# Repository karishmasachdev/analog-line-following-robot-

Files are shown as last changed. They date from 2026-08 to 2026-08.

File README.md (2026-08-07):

# analog-line-following-robot — Custom PCB Design

A line-following robot built entirely from discrete analog components — no microcontroller, no programmable logic. This repo covers the full circuit design and my custom KiCad schematic/PCB layout, built on top of a line-following robot.

## Overview

The robot follows a black line on a white surface using visible-light sensing, analog comparison, and transistor-driven motors — all without any digital logic or code. The signal path has three stages:

- **Sensing** — a pair of LDR (photoresistor) voltage dividers, each paired with a white LED that actively floods the surface below the robot with light
- **Comparison** — the LM358 package's two op-amps are each wired as a comparator using the same left-row and right-row voltages, but with the `+`/`−` inputs swapped between them: one op-amp takes the left row on `+` and the right row on `−`, the other takes the right row on `+` and the left row on `−`. This produces two separate, naturally complementary outputs — one op-amp per motor — instead of a single shared output
- **Actuation** — the comparator output drives BJTs (acting as switches) that control current to two DC gear motors, steering the robot by adjusting each wheel's power independently

## How it works

Each LDR sits in a voltage divider with its own potentiometer, one row for the left sensor and one for the right. When a surface reflects more light back into an LDR, that LDR's resistance drops and its row's voltage falls; over the black line, less light returns, resistance rises, and the row's voltage climbs. The two rows are compared directly against each other rather than against a fixed threshold.

Each op-amp takes the left row's voltage and the right row's voltage as its two inputs, but with the `+` and `−` connections reversed relative to the other op-amp. Because of that reversal, when one side reads higher than the other, the two op-amp outputs snap in opposite directions — one goes high while the other goes low — rather than passing through a slow analog gradient. Each output feeds the base of its own NPN BJT, switching that motor's current on or off. Flyback diodes across each motor protect the transistors from voltage spikes when the motor switches off, and electrolytic capacitors across the power rails smooth out ripple from the motors starting and stopping.

Because the two op-amp outputs are naturally complementary (one high while the other is low, and vice versa), the two motors respond oppositely to the same left-vs-right comparison: when the robot drifts and one sensor row reads higher relative to the other, one motor speeds up while the other slows or stops, steering the robot back onto the line.

## Repo contents

```
├── kicad/              KiCad project, schematic, and PCB layout files
├── images/
│   ├── schematic.png
│   ├── pcb-layout.png
│   └── 3d-render.png
└── media/
    └── demo-video link
```

## Schematic

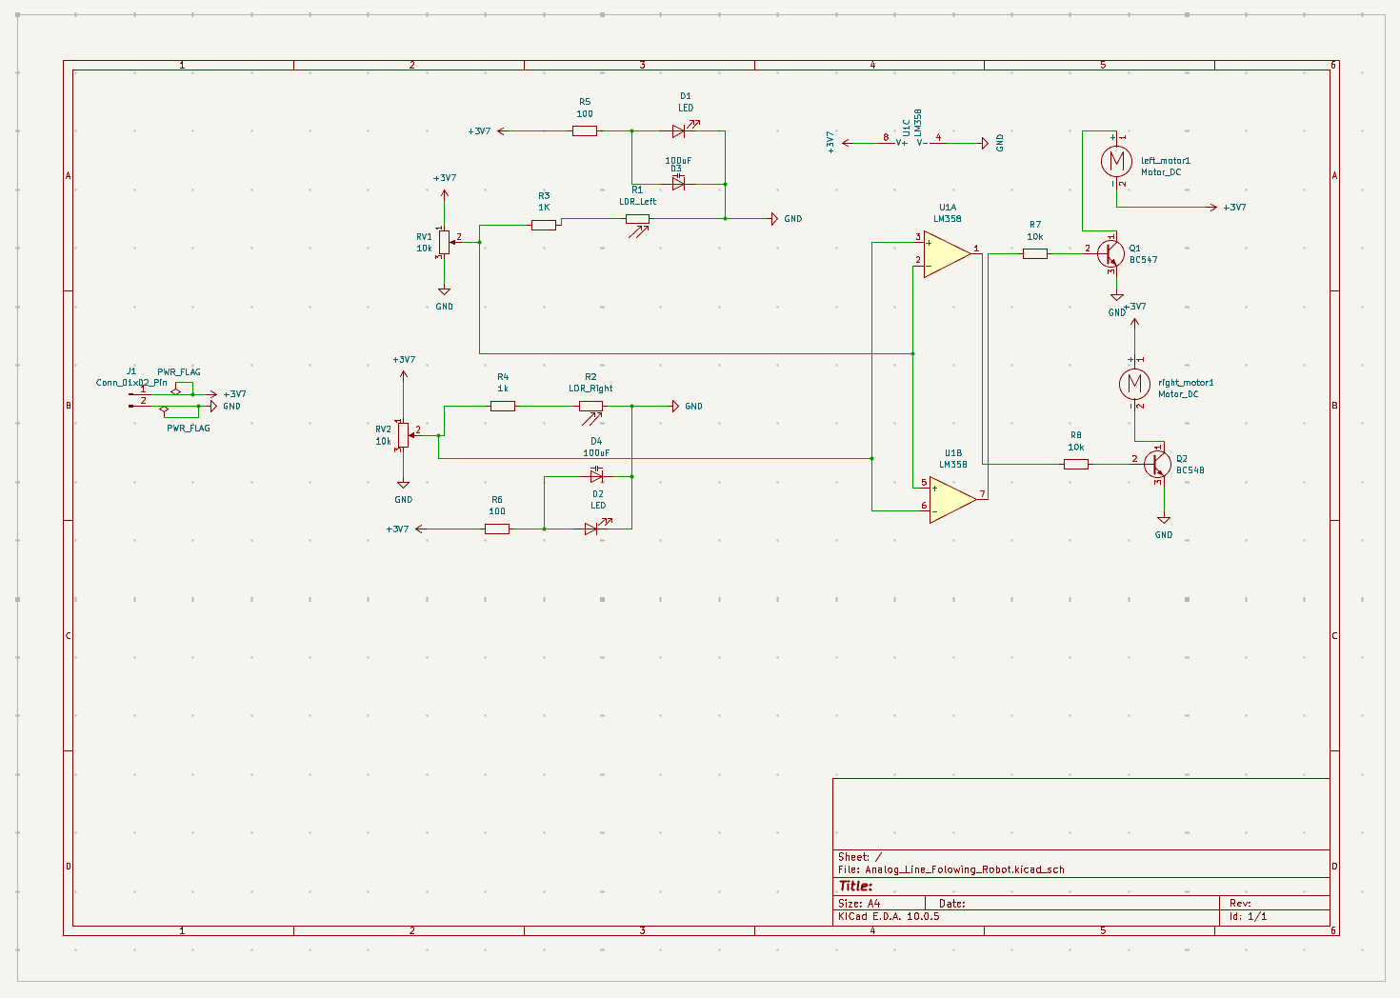
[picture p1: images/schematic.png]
schematic


## PCB layout (routed)

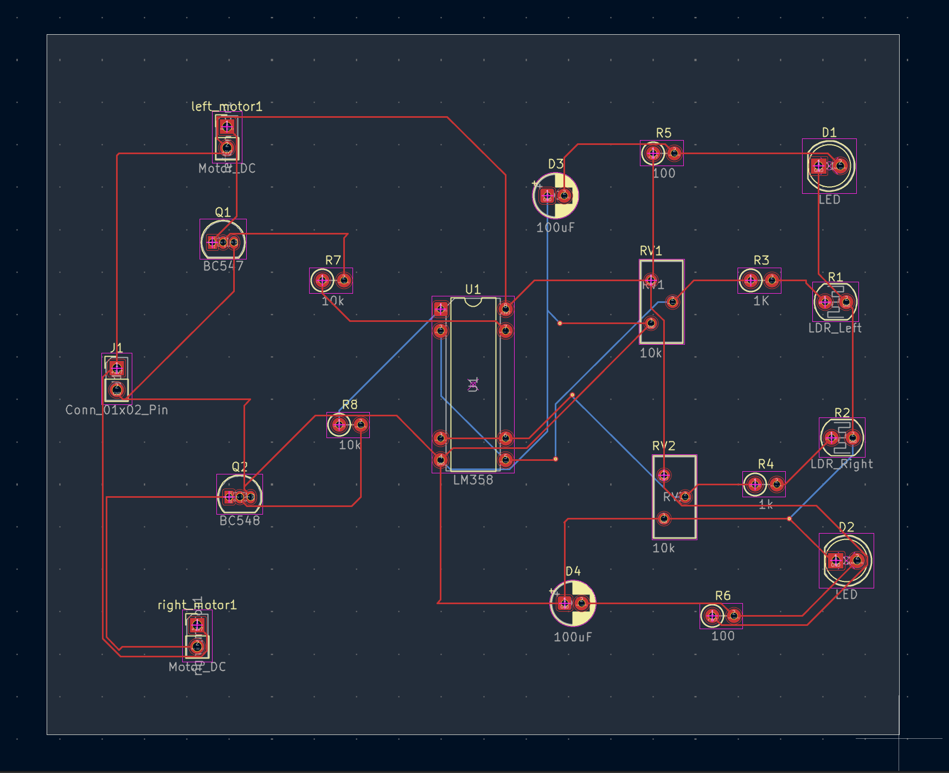
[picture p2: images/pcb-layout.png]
PCB layout


## 3D render

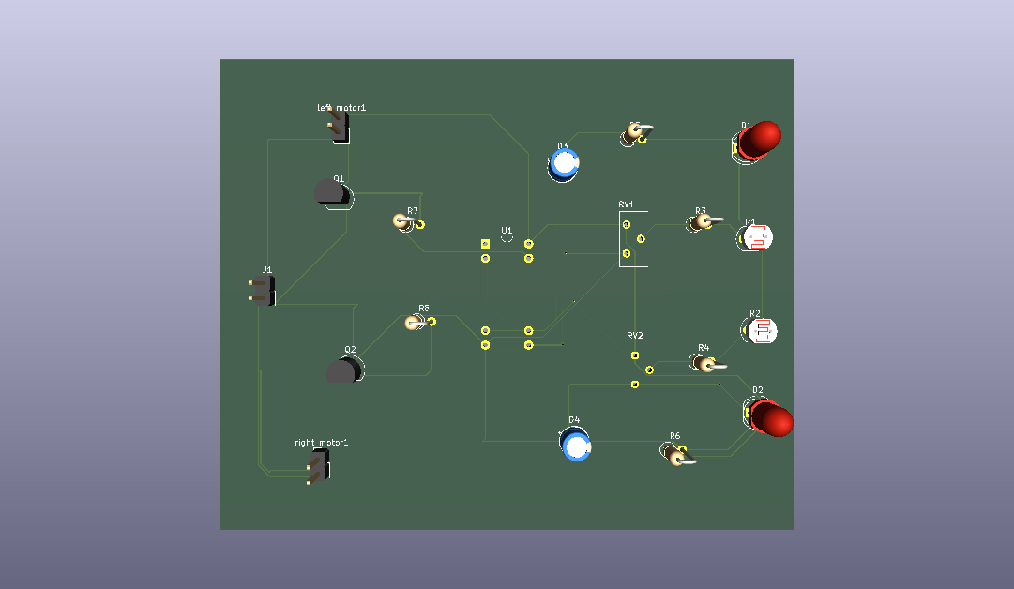
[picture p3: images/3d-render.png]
3D render


## Demo

https://github.com/user-attachments/assets/1498a725-2bcb-41b3-9672-68c0f6f58ff7

## Key components

| Part | Role |
|---|---|
| LM358 dual op-amp | Voltage comparator, two channels wired with reversed inputs |
| CdS photoresistor (LDR) x2 | Reflected-light sensing |
| White LED x2 | Active illumination of the surface |
| PN2222 NPN BJT x2 | Motor switching stage |
| N20 gear motor x2 | Differential drive |
| 10k potentiometer x2 | Sensor calibration / balancing |
| 1N4001 diode x2 | Motor flyback protection |
| 100µF electrolytic capacitor x2 | Power rail smoothing |

## Tools used

- KiCad (schematic capture, PCB layout, ERC/DRC)
- LTspice (circuit simulation, sensor and comparator characterization)
- Oscilloscope (hardware verification of LED/motor drive signals)
- Soldering iron (hand-soldered sensor and wiring connections)

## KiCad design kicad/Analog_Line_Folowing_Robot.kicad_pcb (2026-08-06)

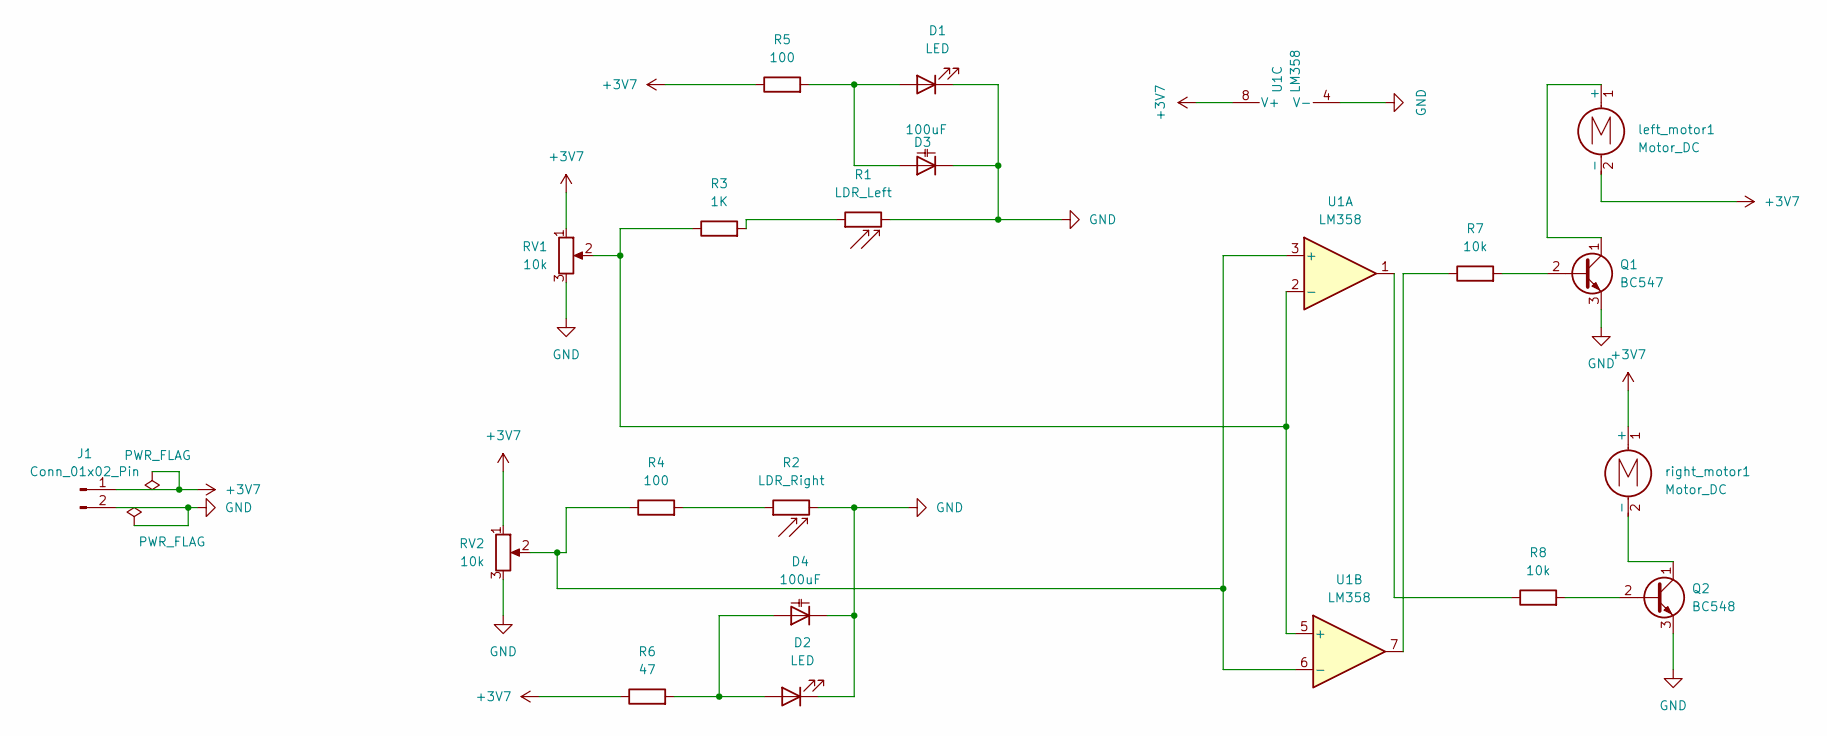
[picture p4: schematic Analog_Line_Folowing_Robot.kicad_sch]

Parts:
D1, D2: LED; LED_D5.0mm
D3, D4: 100uF; CP_Radial_D5.0mm_P2.00mm
J1: Conn_01x02_Pin; PinHeader_1x02_P2.54mm_Vertical
Q1: BC547; TO-92_Inline
Q2: BC548; TO-92_Inline
R1: LDR_Left; R_LDR_4.9x4.2mm_P2.54mm_Vertical
R2: LDR_Right; R_LDR_4.9x4.2mm_P2.54mm_Vertical
R3: 1K; R_Axial_DIN0207_L6.3mm_D2.5mm_P2.54mm_Vertical
R4, R5: 100; R_Axial_DIN0207_L6.3mm_D2.5mm_P2.54mm_Vertical
R6: 47; R_Axial_DIN0207_L6.3mm_D2.5mm_P2.54mm_Vertical
R7, R8: 10k; R_Axial_DIN0207_L6.3mm_D2.5mm_P2.54mm_Vertical
RV1, RV2: 10k; Potentiometer_Bourns_3386X_Horizontal
U1: LM358; DIP-8-16_W7.62mm
left_motor1: Motor_DC; PinHeader_1x02_P2.54mm_Vertical
right_motor1: Motor_DC; PinHeader_1x02_P2.54mm_Vertical

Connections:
+3V7: J1.1, R5.1, R6.1, RV1.1, RV2.1, U1.8 (V+), left_motor1.2 (-), right_motor1.1 (+)
GND: D1.1 (K), D2.1 (K), D3.1 (K), D4.1 (K), J1.2, Q1.3 (E), Q2.3 (E), R1.2, R2.2, RV1.3, RV2.3, U1.4 (V-)
unnamed: D1.2 (A), D3.2 (A), R5.2
unnamed: D2.2 (A), D4.2 (A), R6.2
unnamed: Q1.2 (B), R7.2
unnamed: Q1.1 (C), left_motor1.1 (+)
unnamed: Q2.2 (B), R8.2
unnamed: Q2.1 (C), right_motor1.2 (-)
unnamed: R1.1, R3.2
unnamed: R2.1, R4.2
unnamed: R7.1, U1.7
unnamed: R8.1, U1.1
unnamed: R4.1, RV2.2, U1.3 (+), U1.6 (-)
unnamed: R3.1, RV1.2, U1.2 (-), U1.5 (+)

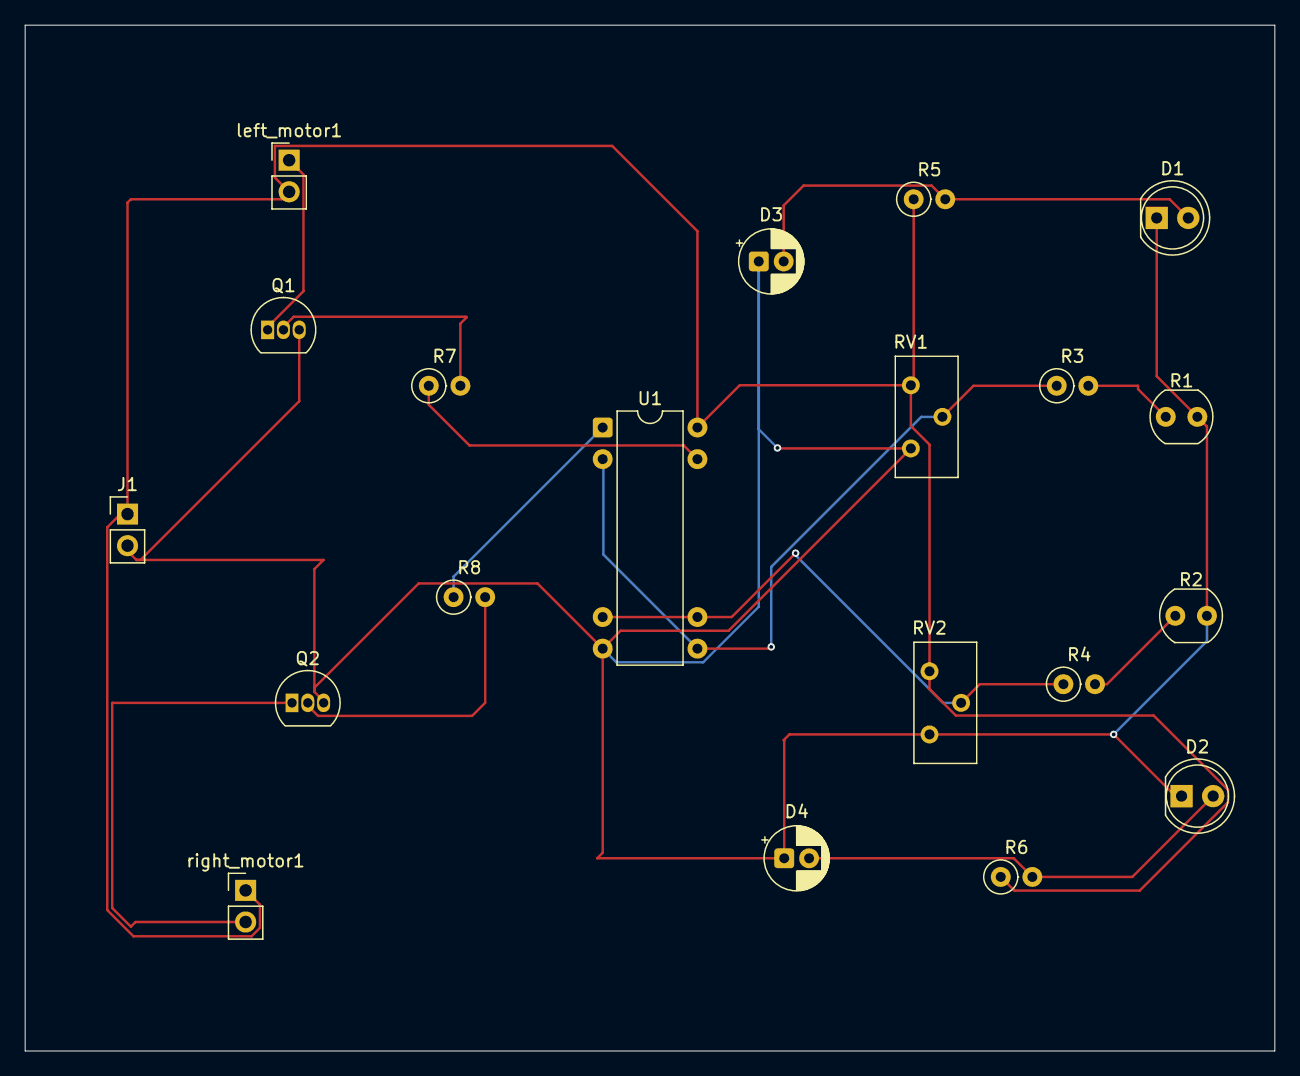
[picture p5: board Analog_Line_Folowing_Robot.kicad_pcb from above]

Board: 2 copper layers, 100.5 x 82.5 mm, 20 parts (0 on the bottom side), 14 nets.

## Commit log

2026-08-06 Create kicad
2026-08-06 Replace schematic image with local file reference
    Updated schematic image reference in README.
